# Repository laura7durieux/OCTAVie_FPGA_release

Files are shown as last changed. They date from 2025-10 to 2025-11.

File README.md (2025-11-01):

# OCTAVie – Ultrasonic Acquisition Platform

**OCTAVie** is an open-source hardware and software platform designed to capture and analyze ultrasonic vocalizations of animals (up to ≥80 kHz).  
It combines a sensitive microphone module, an analog front-end, an FPGA-based acquisition unit, and a PC application for real-time spectral analysis.

This repository hosts the **complete open-source design files**: electronics, enclosures, FPGA firmware, PC software, documentation, and example datasets.  
The project is developed at **ICube, LNCA, and the Faculty of Physics and Engineering – Strasbourg, France**, within the framework of the **OCTAVie project**.

---

## Quickstart

### 1. Build Hardware
- Go to [hardware/](hardware/)  
- Assemble the **microphone** and the **acquisition unit** following the build guide:  
  - [docs/build_guide/pcb_assembly.md](docs/build_guide/pcb_assembly.md)  
  - [docs/build_guide/mechanical_assembly.md](docs/build_guide/mechanical_assembly.md)  
- Complete system integration: [hardware/system_integration/final_assembly.md](hardware/system_integration/final_assembly.md)

### 2. Program FPGA
- Go to [firmware_fpga/](firmware_fpga/)  
- Compile the project in Quartus (or use provided bitstreams in [releases/](releases/))  
- Load bitstream on Cyclone V GX using Quartus Programmer

### 3. Run PC Application
- Go to [software_pc/](software_pc/)  
- Install dependencies
- Run the software

### Documentation
- Build guide → docs/build_guide/
- User guide → docs/user_guide/user_manual.md
- Validation & tests → docs/validation/
- BOM → docs/publication_assets/tables/bom_master_v1.0.csv

### Citation
If you use this project, please cite the associated HardwareX article and Zenodo DOI:
10.5281/zenodo.17356089

### License
- Hardware → CERN OHL-S v2.0
- Software → GPL-3.0
- Documentation → CC BY-SA 4.0
(see LICENSES/)

---

## Repository Structure
Please see the document : File_list_V1.xlsx 
This document regroups all the documents available in this project as well as their localisation and their status.

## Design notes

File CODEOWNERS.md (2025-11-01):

### `CODEOWNERS`  
# This file defines code owners for automatic review assignment.

# Root files and general documentation
/ @LauraDurieux

# Hardware (PCB, CAD)
/hardware/ @LauraDurieux 

# FPGA firmware
/firmware_fpga/ @LauraDurieux

# PC software
/software_pc/ @JeanBaptisteK

# Documentation
/docs/ @LauraDurieux

# Default owner
* @LauraDurieux

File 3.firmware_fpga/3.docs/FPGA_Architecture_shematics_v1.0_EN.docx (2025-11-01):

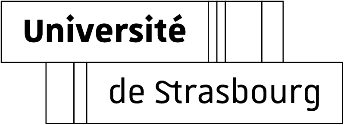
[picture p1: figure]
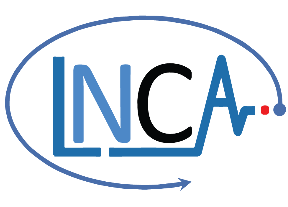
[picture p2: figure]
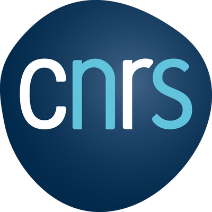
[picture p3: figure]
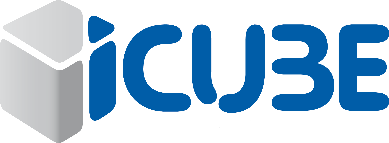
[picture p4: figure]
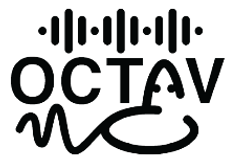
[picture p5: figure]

ie

L. Durieux

Abstract

This document presents an overview of the FPGA design implemented in Intel Quartus. Since the complete project files cannot be shared due to proprietary IP content, only a visual capture of the Quartus design is provided. The image illustrates the top-level architecture and interconnections between the main logic blocks used in the OCTAVie system, including acquisition, FFT processing, and communication modules. This overview aims to give readers a clear understanding of the FPGA design structure while respecting intellectual property constraints.

FPGA architecture schematic

English – v1.0

# Section 1 — FPGA Quartus schematic full view

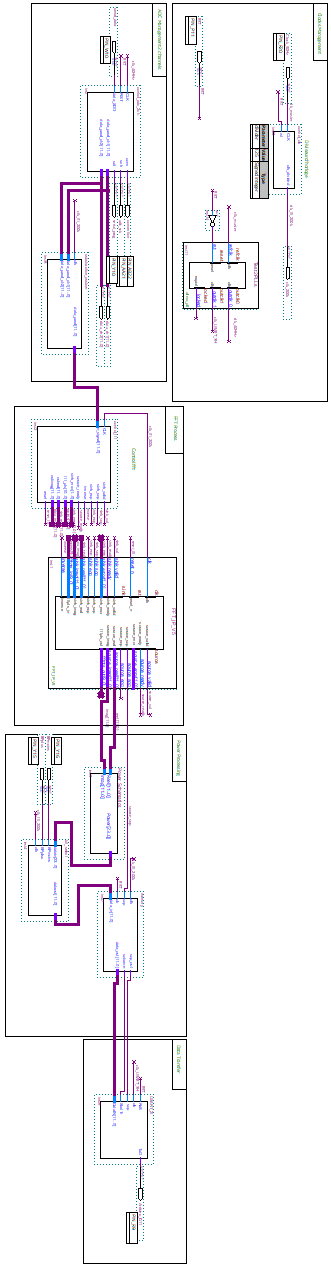
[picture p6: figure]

# Section 2 – Details on the subblocks

## Clocks management

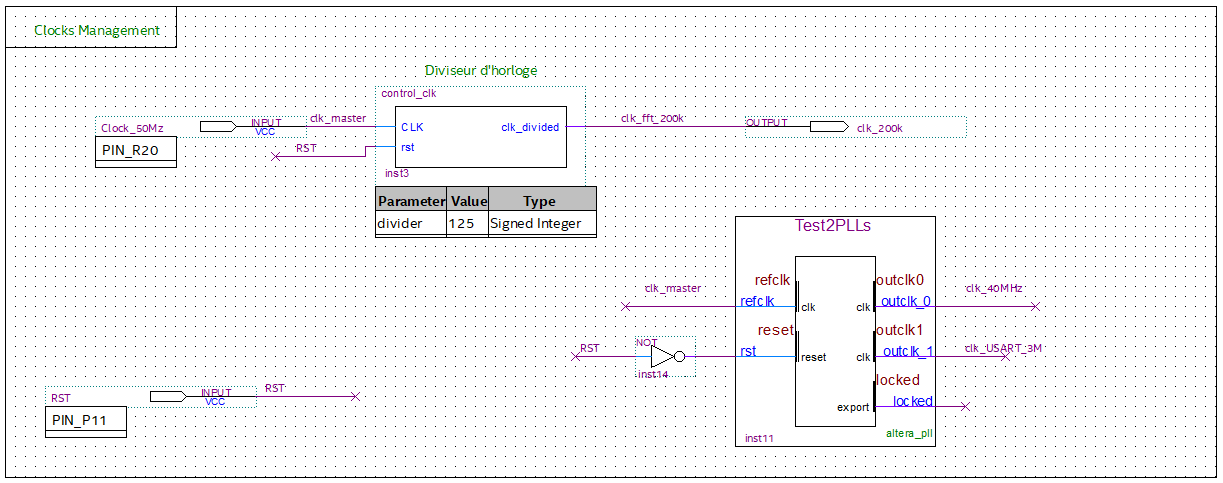
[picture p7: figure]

## ADC management 2channels

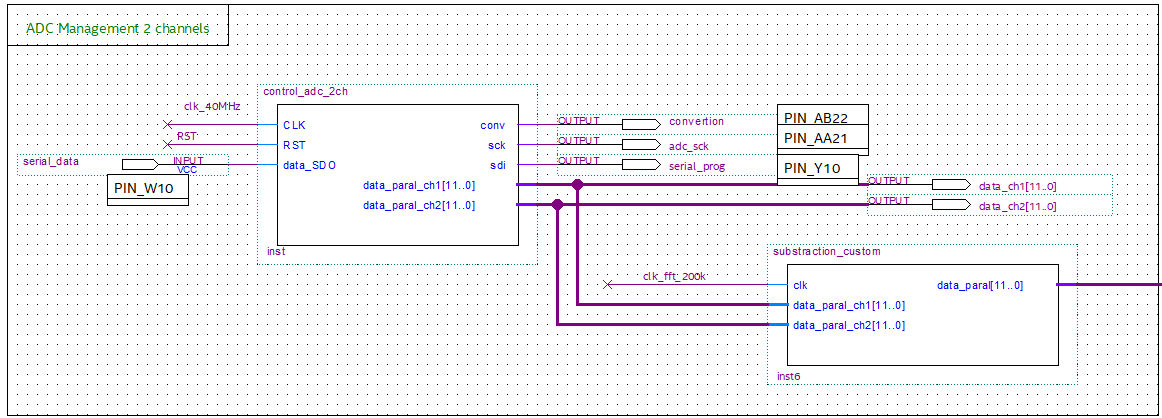
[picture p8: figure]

## FFT Process

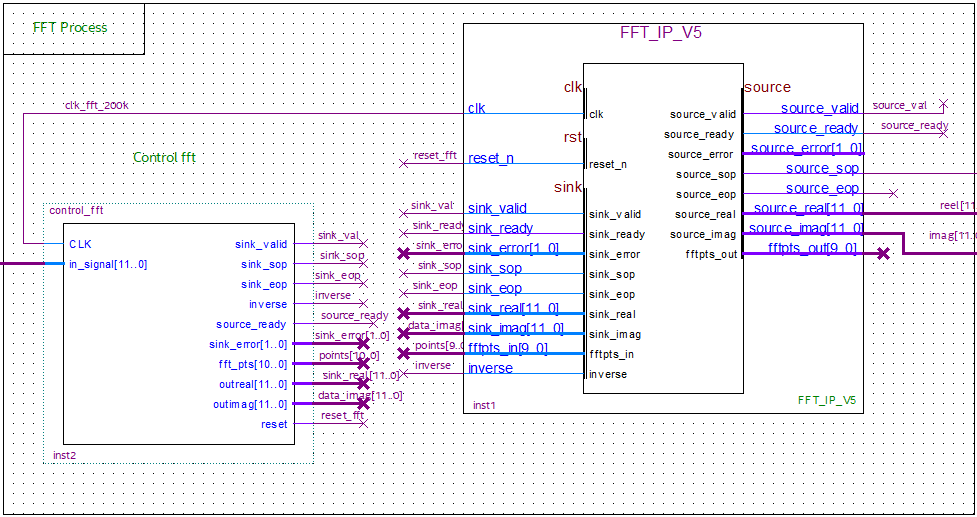
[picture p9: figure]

## Power processing

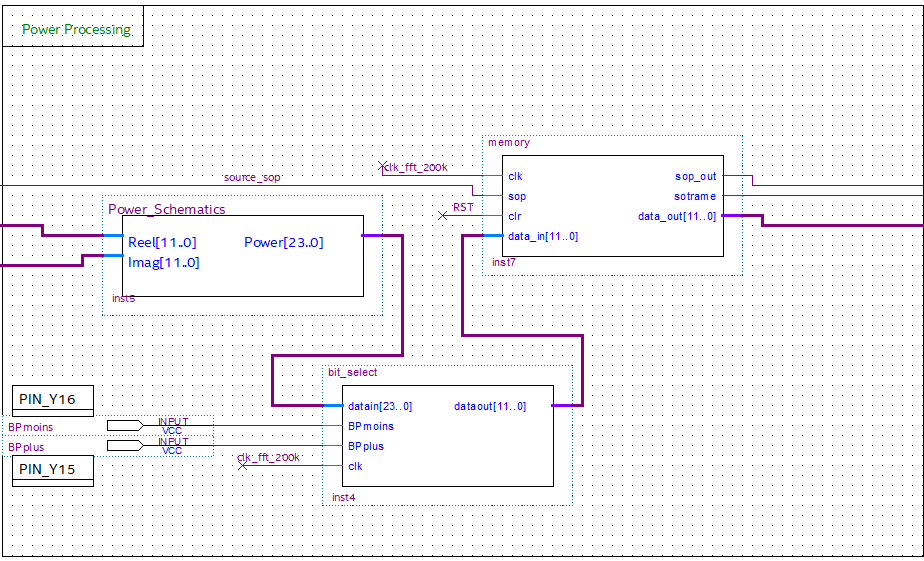
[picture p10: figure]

Inside Power Schematics:

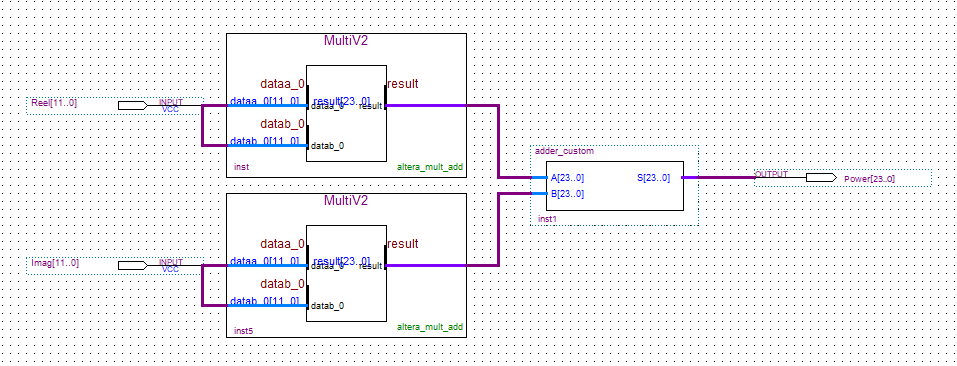
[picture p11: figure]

## Data Transfer

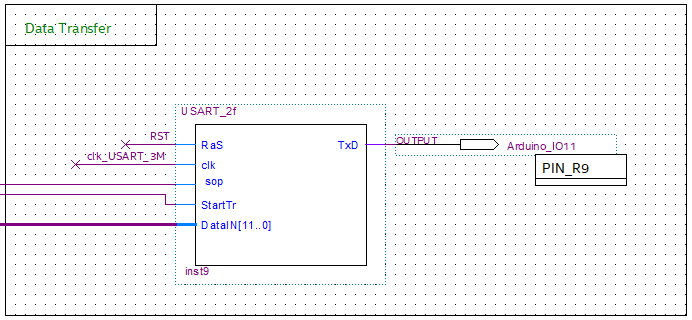
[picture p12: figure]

# Section 3 – list of the available modules

- adder_custom.vhd

Performs a simple 24-bit unsigned addition between two input vectors. Used for internal arithmetic operations such as sample accumulation or amplitude scaling.

- bit_select.vhd

Implements a dynamic bit-window selector controlled by two push buttons. Allows the user to manually choose a 12-bit slice within a 24-bit signal, useful for debugging or signal inspection.

- control_adc_2ch.vhd

Controls a two-channel ADC via a bit-banged SPI protocol. Manages conversion timing, serial data readout, and channel configuration for alternating acquisition between channel 1 and channel 2.

- control_clk.vhd

A simple clock divider generating a lower-frequency clock from the main 50 MHz input. Used to derive timing signals for slower subsystems such as the ADC interface or FFT logic.

- control_fft.vhd

Generates the control interface for an FFT IP core (start, end, valid, and reset).
Feeds the FFT block with real input samples, handles SOP/EOP markers, and produces a short reset pulse during startup.

- memory.vhd

Implements a 256×12-bit synchronous RAM buffer with simultaneous write and read operations. Used to temporarily store and replay sample data, synchronized with a “start of packet” (SOP) trigger.

- substraction_custom.vhd

Performs a signed subtraction between two 12-bit input channels. Used to compute differential signals (e.g., between ADC channels) before FFT processing.

- USART_2f.vhd

Custom two-frame UART transmitter that serializes 12-bit data over two consecutive UART-like frames. Each frame includes start, data, and stop bits, plus embedded SOP flag bits for synchronization.

What is not included are the blocks IP of INTEL Namely:

- MultiV2
- FFT_IP_V5
- Test2PLLs

To be able to redo the full schematic you need to buy these blocks. Note that, to simply program the FPGA with the current version without modifying the function, you can simply use bitstream.

# License Information

Hardware license: CERN Open Hardware License v2 (Strongly Reciprocal – OHL-S).

Software license: GNU General Public License v3 (GPLv3), ensuring that all modifications remain open-source.

Documentation license: Creative Commons Attribution-ShareAlike 4.0 International (CC-BY-SA 4.0).

# Versioning

Authors | Version | Date | Comment
L. Durieux | V1.0 | 29.10.2025 | Document first release
F. STOCK | | 01.11.2025 | Review

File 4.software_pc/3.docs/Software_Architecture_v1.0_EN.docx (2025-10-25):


ie

JB Kammerer

Abstract

This document presents the software architecture of the OCTAVie system. It aims to facilitate the understanding of the provided source code by illustrating the main program flow and interactions between modules through a simplified flowchart. The diagram highlights the sequence from data acquisition and FPGA communication to signal processing, display, and file storage. This overview helps readers grasp the overall logic and structure of the software for easier maintenance, customization, and further development.

Software Architecture

English – v1.0

# Section 1 — Structure Generale

To be completed

# License Information

Hardware license: CERN Open Hardware License v2 (Strongly Reciprocal – OHL-S).

Software license: GNU General Public License v3 (GPLv3), ensuring that all modifications remain open-source.

Documentation license: Creative Commons Attribution-ShareAlike 4.0 International (CC-BY-SA 4.0).

# Versioning

Authors | Version | Date | Comment
JB Kammerer | V1.0 | 25.10.25 | Document first release

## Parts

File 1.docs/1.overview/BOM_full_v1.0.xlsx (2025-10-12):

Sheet: Details
Designator | Component | Number | Cost per unit (€) | Total cost (€) | Source of materials | Material type
Microphone
Electronic component
C1,C4 | C0805C104K5RACTU | 2 | 0.07 | 0.14 | DigiKey | Ceramic
C2,C3,C6 | C0805C105K3RACTU | 3 | 0.1 | 0.3 | DigiKey | Ceramic
C5 | C0805C474K5RACTU | 1 | 0.23 | 0.23 | DigiKey | Ceramic
R1 | AC0805FR-074K7L | 1 | 0.09 | 0.09 | DigiKey | Composite
R2 | RC0805JR-071KL | 1 | 0.1 | 0.1 | DigiKey | Composite
R3 | RC0805JR-0710KL | 1 | 0.09 | 0.09 | DigiKey | Composite
R4 | RC0805JR-071ML | 1 | 0.09 | 0.09 | DigiKey | Composite
R5 | RC0805JR-0718KL | 1 | 0.09 | 0.09 | DigiKey | Composite
R6,R7 | RC0805JR-07100KL | 2 | 0.01 | 0.09 | DigiKey | Composite
D1 | 150080RS75000 | 1 | 0.16 | 0.16 | DigiKey | Semiconductor
IC1 | MCP6021-I/SN | 1 | 1.19 | 1.19 | DigiKey | Semiconductor
U1 | IMP23ABSUTR | 1 | 2.22 | 2.22 | DigiKey | Semiconductor
J1 | B3B-PH-SM4-TB | 1 | 0.45 | 0.45 | DigiKey | Composite
Total |  |  | 4.89 | 5.24
PCBA
PCB Fabrication |  | 1 | 5.98 | 5.98 | JLCPCB | Other
PCB Assembly |  | 1 | 0 | 0 | JLCPCB | Other
Shipping |  | 1 | 18.37 | 18.37 | JLCPCB | Other
Total |  |  | 24.35 | 24.35
System assembly
Sound cable | 8451 010100 | 2 m | 3.44 | 51.61 | DigiKey | Composite
XLR male | AC3MM | 1 | 3.36 | 3.36 | DigiKey | Composite
JST female | PHR-3 | 1 | 0.09 | 0.09 | DigiKey | Composite
Total |  |  | 6.89 | 55.06
Enclosure
3D printing |  | 1 | 2.63 | 2.63
Total |  |  | 12.97 | 61.14
Total Microphone |  |  | 38.76 | 87.28
Analog Signal Board
Electronic component
C1 | 10 µF capacitor (C0805C106K8PACTU) | 1 | 0.11 | 0.11 | DigiKey | Ceramic
C2,C6,C18 | 1 µF capacitor (C0805C105K3RAC7800) | 3 | 0.1 | 0.3 | DigiKey | Ceramic
C3,C14,C26 | 100 nF capacitor (C0805C104M5RAC7800) | 3 | 0.09 | 0.27 | DigiKey | Ceramic
C4,C11,C12,C13,C16,C23,C24,C25 | 1 nF capacitor (C0805C102K1HAC7800) | 8 | 0.09 | 0.72 | DigiKey | Ceramic
C5,C10,C17,C22 | 1.5 nF capacitor (C0805C152K3HAC7800) | 4 | 0.09 | 0.36 | DigiKey | Ceramic
C7,C19 | 100 pF capacitor (C0805C101J5GAC7800) | 2 | 0.07 | 0.14 | DigiKey | Ceramic
C8,C20 | 180 pF capacitor (C0805C181K5GAC7800) | 2 | 0.2 | 0.4 | DigiKey | Ceramic
C9,C21 | 15 nF capacitor (C0805C153K5RAC7800) | 2 | 0.09 | 0.18 | DigiKey | Ceramic
C15,C27 | 470 pF capacitor (C0805C471K5RAC7800) | 2 | 0.09 | 0.18 | DigiKey | Ceramic
J1,J3,J9,J10 | 3-pin JST connector (B3B-XH-A) | 4 | 0.09 | 0.36 | DigiKey | Composite
J2,J4,J5,J13 | 2-pin header (PH1-02-UA) | 4 | 0.09 | 0.36 | DigiKey | Composite
J6,J14 | 2x3-pin header (PH2-06-UA) | 2 | 0.09 | 0.18 | DigiKey | Composite
J7,J8 | 1-pin header (PH1-01-UA) | 2 | 0.08 | 0.16 | DigiKey | Composite
J11 | 8-pin header (PH1-08-UA) | 1 | 0.09 | 0.09 | DigiKey | Composite
J12 | 6-pin JST connector (B6B-XH-A) | 1 | 0.15 | 0.15 | DigiKey | Composite
R1,R2,R3,R4,R11,R12,R20,R24,R26,R27,R28,R29,R36,R37,R43,R48,RV1,RV2 | Resistor 100kΩ (ERJ-P06J104V) | 18 | 0.1 | 1.8 | DigiKey | Other
R5,R6,R30,R31 | Resistor 3.9kΩ (ERJ-P06J392V) | 4 | 0.1 | 0.4 | DigiKey | Other
R7,R32 | Resistor 560Ω (ERJ-P06J561V) | 2 | 0.1 | 0.2 | DigiKey | Other
R8,R10,R33,R35 | Resistor 15kΩ (ERJ-P06J153V) | 4 | 0.1 | 0.4 | DigiKey | Other
R9,R34 | Resistor 1.2kΩ (ERJ-P06J122V) | 2 | 0.1 | 0.2 | DigiKey | Other
R13,R38 | Resistor 5.6kΩ (ERJ-P06J562V) | 2 | 0.1 | 0.2 | DigiKey | Other
R14,R18,R39,R44 | Resistor 82kΩ (ERJ-P06J823V) | 4 | 0.1 | 0.4 | DigiKey | Other
R15,R19,R40,R45 | Resistor 33kΩ (ERJ-P06J333V) | 4 | 0.1 | 0.4 | DigiKey | Other
R16,R25,R42,R50 | Resistor 100Ω (ERJ-P06J101V) | 4 | 0.1 | 0.4 | DigiKey | Other
R17,R21,R23,R41,R46,R47 | Resistor 10kΩ (ERJ-P06J103V) | 6 | 0.1 | 0.6 | DigiKey | Other
R22,R49 | Resistor 1kΩ (ERJ-P06J102V) | 2 | 0.1 | 0.2 | DigiKey | Other
U1,U4 | Integrated Circuit - MCP6022 (dual op amp) | 2 | 1.82 | 3.64 | DigiKey | Semiconductor
U2,U5 | Integrated Circuit - MCP6024 (quad op amp) | 2 | 2.4 | 4.8 | DigiKey | Semiconductor
U3,U6 | Integrated Circuit - MCP6021 (single op amp) | 2 | 1.46 | 2.92 | DigiKey | Semiconductor
H_Uno_10 | 10-pin header (PH1-10-UA) | 1 | 0.12 | 0.12 | DigiKey | Composite
H_Uno_8 | 8-pin header (PH1-08-UA) | 2 | 0.09 | 0.18 | DigiKey | Composite
H_Uno_6 | 6-pin header (PH1-06-UA) | 1 | 0.09 | 0.09 | DigiKey | Composite
Total |  |  | 8.6 | 20.91
PCBA
PCB Fabrication |  | 1 | 5.98 | 5.98 | JLCPCB | Other
PCB Assembly |  | 1 | 0 | 0 | JLCPCB | Other
Shipping |  | 1 | 18.37 | 18.37 | JLCPCB | Other
Total |  |  | 24.35 | 24.35
Total Analog Signal Board |  |  | 32.95 | 45.26
FPGA
Electronic component
FPGA - Cyclone V GX - dev. Kit | P0150 | 1 | 264.63 € | 264.63 € | Mouser | Other
Total |  |  | 264.63 € | 264.63 €
Total FPGA |  |  | 264.63 | 264.63
System
System assembly
FTDI Cable | TTL-234X-3V3 | 1 | 17.35 | 17.35 | DigiKey | Composite
JST female 3 pin | XHP-3 | 3 | 0.09 | 0.27 | DigiKey | Composite
JST female 6 pin | XHP-6 | 1 | 0.064 | 0.064 | DigiKey | Composite
Potentiometer 100kohm | P160KNP-0QD20B100K | 2 | 1.61 | 3.22 | DigiKey | Composite
XLR female | AC3FAHL2-AU-PRE | 2 | 1.27 | 2.54 | DigiKey | Composite
Total |  |  | 20.38 | 23.44
Enclosure
3D printing |  | 1 | 36.87 | 36.87
Total |  |  | 36.87 | 36.87
Total System |  |  | 90.20 | 105.57
Grand Total |  |  | 426.54 | 502.74

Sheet: Sheet1
Designator | Number | Cost per unit (€) | Total cost (€) | Source of materials | Material type
Microphone
Electronic component | 1 | 4.89 | 5.24 | Digikey | Other
PCBA | 1 | 24.35 | 24.35 | JLCPCB | Other
System assembly | 1 | 6.89 | 55.06 | Digikey | Other
Enclosure | 1 | 12.97 | 61.14 | JLCPCB | Other
Analog Signal Board
Electronic component | 1 | 8.6 | 20.91 | Digikey | Other
PCBA | 1 | 24.35 | 24.35 | JLCPCB | Other
FPGA
Electronic component | 1 | 264.63 € | 264.63 € | Mouser | Other
System
System assembly | 1 | 20.38 | 23.44 | Digikey | Other
Enclosure | 1 | 36.87 | 36.87 | JLCPCB | Other
Total
 |  | 403.94 | 515.99

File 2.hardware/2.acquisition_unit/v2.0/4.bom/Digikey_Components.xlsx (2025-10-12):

Index | Quantité | Référence | Référence fabricant | Description | Référence client | Disponible | Articles différés | Prix unitaire | Prix calculé EUR
1 | 1 | 732-8491-1-ND | 865080243008 | CAP ALUM 150UF 20% 10V SMD |  | 1 | 0 | 0.26 | 0.26
2 | 1 | 732-8412-1-ND | 865080340002 | CAP ALUM 15UF 20% 16V SMD |  | 1 | 0 | 0.16 | 0.16
3 | 3 | 399-C0805C105K3RACTUCT-ND | C0805C105K3RACTU | CAP CER 1UF 25V X7R 0805 |  | 3 | 0 | 0.1 | 0.30
4 | 8 | 399-C0805C102K1HACTUCT-ND | C0805C102K1HACTU | CAP CER 1000PF 100V X8R 0805 |  | 8 | 0 | 0.09 | 0.72
5 | 4 | 399-C0805C152K3HACTUCT-ND | C0805C152K3HACTU | CAP CER 1500PF 25V X8R 0805 |  | 4 | 0 | 0.09 | 0.36
6 | 2 | 399-C0805C101J5GACTUCT-ND | C0805C101J5GACTU | CAP CER 100PF 50V C0G/NP0 0805 |  | 2 | 0 | 0.07 | 0.14
7 | 2 | 399-C0805C181K5GACTUCT-ND | C0805C181K5GACTU | CAP CER 180PF 50V C0G/NP0 0805 |  | 2 | 0 | 0.2 | 0.40
8 | 2 | 399-C0805C153K5RACTUCT-ND | C0805C153K5RACTU | CAP CER 0.015UF 50V X7R 0805 |  | 2 | 0 | 0.09 | 0.18
9 | 2 | 399-C0805C104M5RACTUCT-ND | C0805C104M5RACTU | CAP CER 0.1UF 50V X7R 0805 |  | 2 | 0 | 0.09 | 0.18
10 | 2 | 399-C0805C471K5RACTUCT-ND | C0805C471K5RACTU | CAP CER 470PF 50V X7R 0805 |  | 2 | 0 | 0.09 | 0.18
11 | 2 | 455-2248-ND | B3B-XH-A | CONN HEADER VERT 3POS 2.5MM |  | 2 | 0 | 0.11 | 0.22
12 | 2 | 2057-PH1-03-UA-ND | PH1-03-UA | CONN HEADER VERT 3POS 2.54MM |  | 2 | 0 | 0.09 | 0.18
13 | 1 | 2057-PH1-02-UA-ND | PH1-02-UA | CONN HEADER VERT 2POS 2.54MM |  | 1 | 0 | 0.09 | 0.09
14 | 3 | 2057-PH1-02-UA-ND | PH1-02-UA | CONN HEADER VERT 2POS 2.54MM |  | 3 | 0 | 0.09 | 0.27
15 | 2 | 2057-PH2-06-UA-ND | PH2-06-UA | CONN HEADER VERT 6POS 2.54MM |  | 2 | 0 | 0.1 | 0.20
16 | 2 | 2057-PH1-01-UA-ND | PH1-01-UA | CONN HEADER VERT 1POS 2.54MM |  | 2 | 0 | 0.09 | 0.18
17 | 1 | 2057-PH1-08-UA-ND | PH1-08-UA | CONN HEADER VERT 8POS 2.54MM |  | 1 | 0 | 0.09 | 0.09
18 | 1 | 2057-PH1-06-UA-ND | PH1-06-UA | CONN HEADER VERT 6POS 2.54MM |  | 1 | 0 | 0.09 | 0.09
19 | 18 | P100KADCT-ND | ERJ-P06J104V | RES SMD 100K OHM 5% 1/2W 0805 |  | 18 | 0 | 0.05 | 0.90
20 | 4 | P3.9KADCT-ND | ERJ-P06J392V | RES SMD 3.9K OHM 5% 1/2W 0805 |  | 4 | 0 | 0.1 | 0.40
21 | 2 | P560ADCT-ND | ERJ-P06J561V | RES SMD 560 OHM 5% 1/2W 0805 |  | 2 | 0 | 0.1 | 0.20
22 | 4 | P15KADCT-ND | ERJ-P06J153V | RES SMD 15K OHM 5% 1/2W 0805 |  | 4 | 0 | 0.1 | 0.40
23 | 2 | P1.2KADCT-ND | ERJ-P06J122V | RES SMD 1.2K OHM 5% 1/2W 0805 |  | 2 | 0 | 0.1 | 0.20
24 | 2 | P5.6KADCT-ND | ERJ-P06J562V | RES SMD 5.6K OHM 5% 1/2W 0805 |  | 2 | 0 | 0.1 | 0.20
25 | 4 | P82KADCT-ND | ERJ-P06J823V | RES SMD 82K OHM 5% 1/2W 0805 |  | 4 | 0 | 0.1 | 0.40
26 | 4 | P33KADCT-ND | ERJ-P06J333V | RES SMD 33K OHM 5% 1/2W 0805 |  | 4 | 0 | 0.1 | 0.40
27 | 4 | P100ADCT-ND | ERJ-P06J101V | RES SMD 100 OHM 5% 1/2W 0805 |  | 4 | 0 | 0.1 | 0.40
28 | 6 | P10KADCT-ND | ERJ-P06J103V | RES SMD 10K OHM 5% 1/2W 0805 |  | 6 | 0 | 0.1 | 0.60
29 | 2 | P1.0KADCT-ND | ERJ-P06J102V | RES SMD 1K OHM 5% 1/2W 0805 |  | 2 | 0 | 0.1 | 0.20
30 | 2 | MCP6022T-I/SNCT-ND | MCP6022T-I/SN | IC OPAMP GP 2 CIRCUIT 8SOIC |  | 2 | 0 | 1.55 | 3.10
31 | 2 | MCP6024-I/SL-ND | MCP6024-I/SL | IC OPAMP GP 4 CIRCUIT 14SOIC |  | 2 | 0 | 2.24 | 4.48
32 | 2 | MCP6021-I/SN-ND | MCP6021-I/SN | IC OPAMP GP 1 CIRCUIT 8SOIC |  | 2 | 0 | 1.19 | 2.38

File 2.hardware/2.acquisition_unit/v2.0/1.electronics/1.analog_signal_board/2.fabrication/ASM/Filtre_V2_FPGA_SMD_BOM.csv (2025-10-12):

 | Sourced | Placed | References | Value | Footprint | Quantity
1 |  |  | C4, C11, C12, C13, C16, C23, C24, C25 | 1nF | C_0805_2012Metric | 8
2 |  |  | C5, C10, C17, C22 | 1.5nF | C_0805_2012Metric | 4
3 |  |  | C2, C6, C18 | 1µF | C_0805_2012Metric | 3
4 |  |  | C3, C14, C26 | 100nF | C_0805_2012Metric | 3
5 |  |  | C7, C19 | 100pF | C_0805_2012Metric | 2
6 |  |  | C8, C20 | 180pF | C_0805_2012Metric | 2
7 |  |  | C9, C21 | 15nF | C_0805_2012Metric | 2
8 |  |  | C15, C27 | 470pF | C_0805_2012Metric | 2
9 |  |  | C1 | 10µF | C_0805_2012Metric | 1
10 |  |  | R1, R2, R3, R4, R11, R12, R20, R24, R26, R27, R28, R29, R36, R37, R43, R48, RV1, RV2 | 100k | R_0805_2012Metric, JST_XH_B3B-XH-AM_1x03_P2.50mm_Vertical | 18
11 |  |  | R17, R21, R23, R41, R46, R47 | 10k | R_0805_2012Metric | 6
12 |  |  | R5, R6, R30, R31 | 3.9k | R_0805_2012Metric | 4
13 |  |  | R8, R10, R33, R35 | 15k | R_0805_2012Metric | 4
14 |  |  | R14, R18, R39, R44 | 82k | R_0805_2012Metric | 4
15 |  |  | R15, R19, R40, R45 | 33k | R_0805_2012Metric | 4
16 |  |  | R16, R25, R42, R50 | 100 | R_0805_2012Metric | 4
17 |  |  | R7, R32 | 560 | R_0805_2012Metric | 2
18 |  |  | R9, R34 | 1.2k | R_0805_2012Metric | 2
19 |  |  | R13, R38 | 5.6k | R_0805_2012Metric | 2
20 |  |  | R22, R49 | 1k | R_0805_2012Metric | 2
21 |  |  | U1, U4 | MCP6L02x-xMS | SOIC-8_3.9x4.9mm_P1.27mm | 2
22 |  |  | U2, U5 | MCP6L04x-xSL | SOIC-14_3.9x8.7mm_P1.27mm | 2
23 |  |  | U3, U6 | MCP6L91RT-ESN | SOIC-8_3.9x4.9mm_P1.27mm | 2
24 |  |  | A1 | Arduino_UNO_R3 | Arduino_UNO_R3 | 1
25 |  |  | J1, J3, J9, J10 | Conn_01x03_Socket | JST_XH_B3B-XH-AM_1x03_P2.50mm_Vertical, PinHeader_1x03_P2.54mm_Vertical | 4
26 |  |  | J4, J5, J13 | Conn_01x02_Pin | PinHeader_1x02_P2.54mm_Vertical, PinSocket_1x02_P2.54mm_Vertical | 3
27 |  |  | J6, J14 | Conn_02x03_Top_Bottom | PinHeader_2x03_P2.54mm_Vertical | 2
28 |  |  | J7, J8 | Conn_01x01_Pin | PinHeader_1x01_P2.54mm_Vertical | 2
29 |  |  | J2 | Conn_01x02_Socket | PinHeader_1x02_P2.54mm_Vertical | 1
30 |  |  | J11 | Conn_01x08_Socket | PinHeader_1x08_P2.54mm_Vertical | 1
31 |  |  | J12 | Conn_01x06_Socket | PinHeader_1x06_P2.54mm_Vertical | 1

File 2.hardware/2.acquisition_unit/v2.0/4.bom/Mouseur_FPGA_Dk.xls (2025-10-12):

PANIER
Ceci n'est pas une facture
25-août-25 01:42:36
 | N° Mouser | N° de fab. | Fabricant | N° client | Description | RoHS | Cycle de vie | Qté. | Prix (EUR) | Ext. : (EUR)
1 | 993-P0150 | P0150 | Terasic |  | Outils de développement de circuits intégrés logiques programmables Cyclone V GX Starter Kit | RoHS : conforme |  | 2 | 264,63 € | 529,26 €
En soumettant votre commande, vous acceptez ces conditions. (https://www.mouser.fr/saleterms) |  |  |  |  |  |  |  |  | Marchandise : | 529,26 €
Les prix sont ceux de la date et de l'heure indiquées. |  |  |  |  |  |  |  |  | Frais d'expédition : | 0,00 €

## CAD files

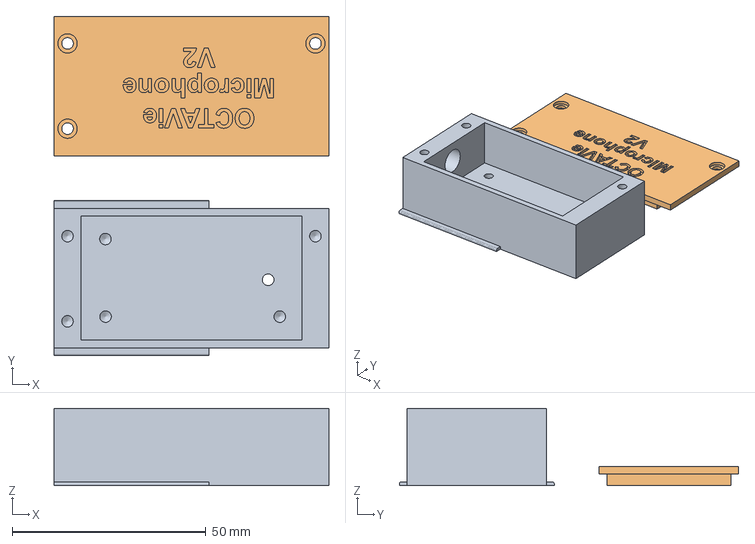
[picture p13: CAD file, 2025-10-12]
7.releases/1.microphone/2.enclosure/Full_Enclosure_v1.0.3mf
71.0 x 87.6 x 20.0 mm
Box.stl
Couvercle.stl

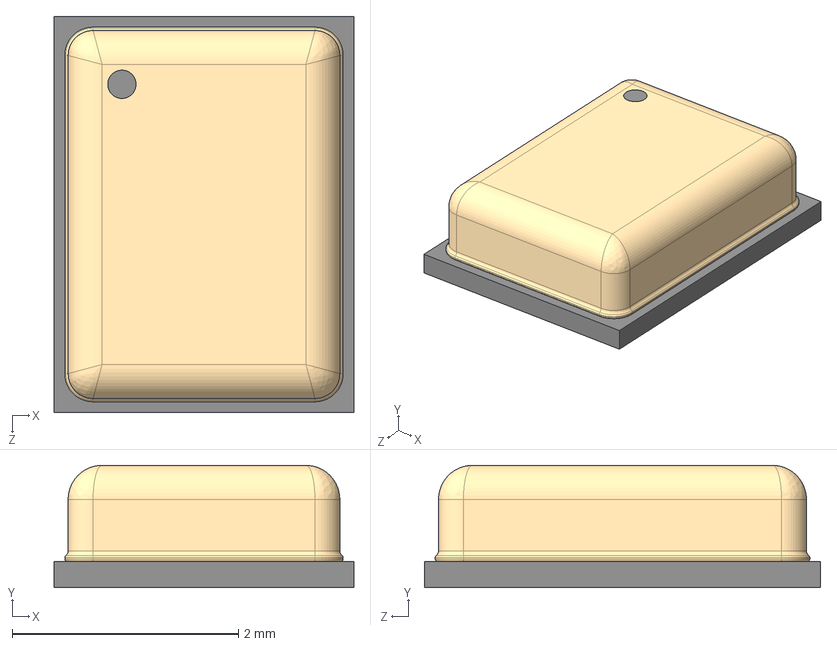
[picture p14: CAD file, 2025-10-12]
2.hardware/1.microphone/v1.0/1.electronics/1.pcb_design/IMP23ABSUTR/IMP23ABSUTR.step
2.65 x 1.08 x 3.50 mm

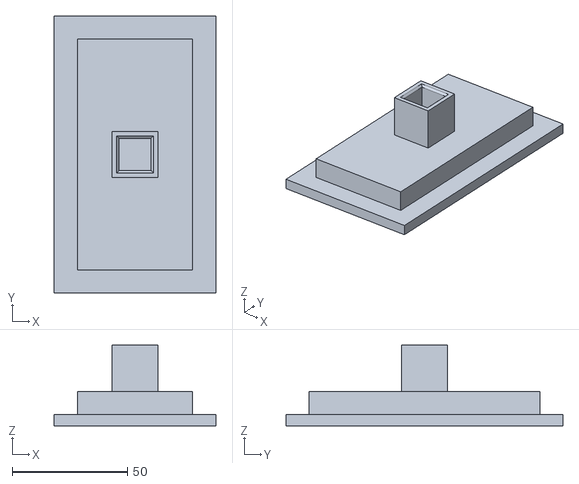
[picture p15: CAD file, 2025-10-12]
2.hardware/1.microphone/v1.0/2.enclosure/1.cad/Support_Foot_v1.0.stl
70.0 x 120.0 x 35.0

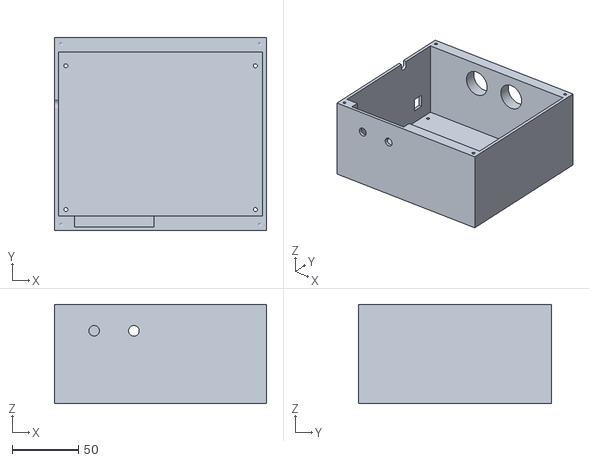
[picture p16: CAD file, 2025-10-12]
2.hardware/2.acquisition_unit/v2.0/2.enclosure/1.cad/BoiteFPGA_Body_v1.0.stl
160.0 x 146.0 x 75.0

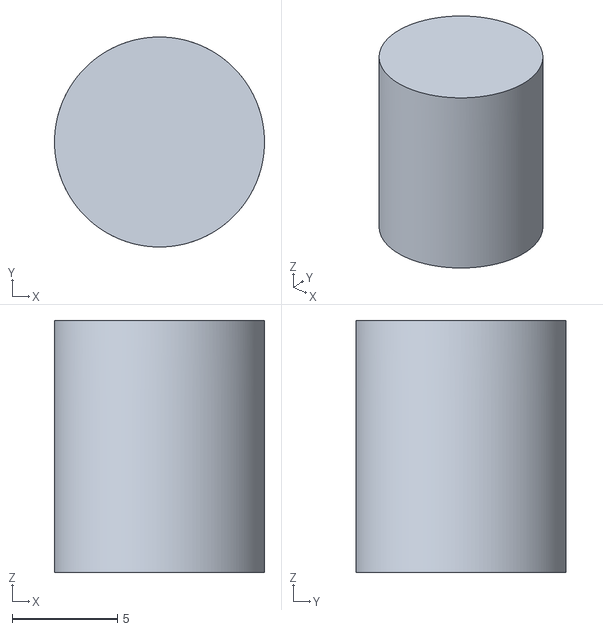
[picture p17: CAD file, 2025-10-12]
7.releases/2.acquisition_unit/2.enclosure/BoiteFPGA_ButtonPotentiometre_v1.0.stl
10.0 x 10.00 x 12.0

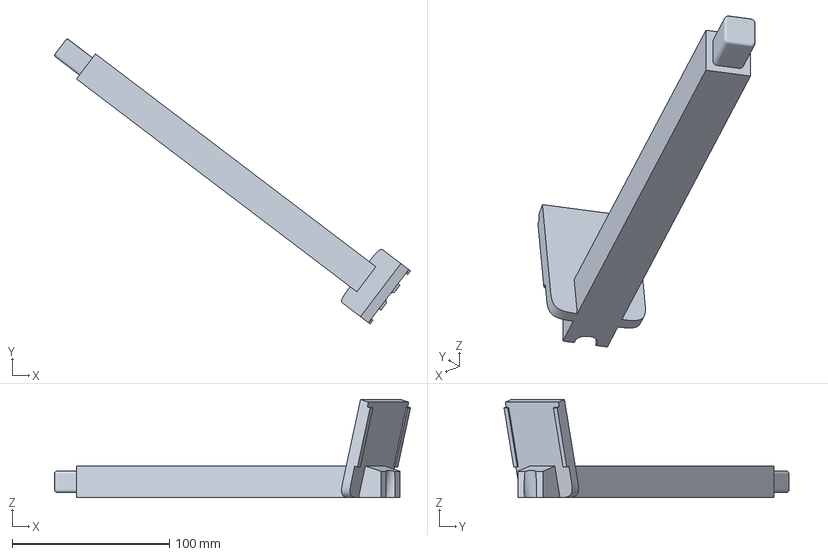
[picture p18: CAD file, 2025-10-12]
2.hardware/1.microphone/v1.0/2.enclosure/1.cad/Support_v1.0.3mf
226.2 x 181.1 x 62.3 mm

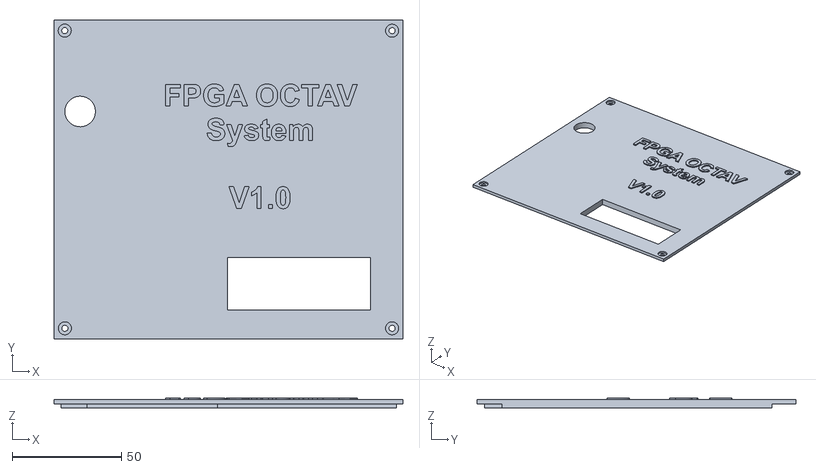
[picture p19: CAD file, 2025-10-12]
2.hardware/2.acquisition_unit/v2.0/2.enclosure/1.cad/BoiteFPGA_Couvercle_v1.0.stl
159.8 x 146.3 x 4.70

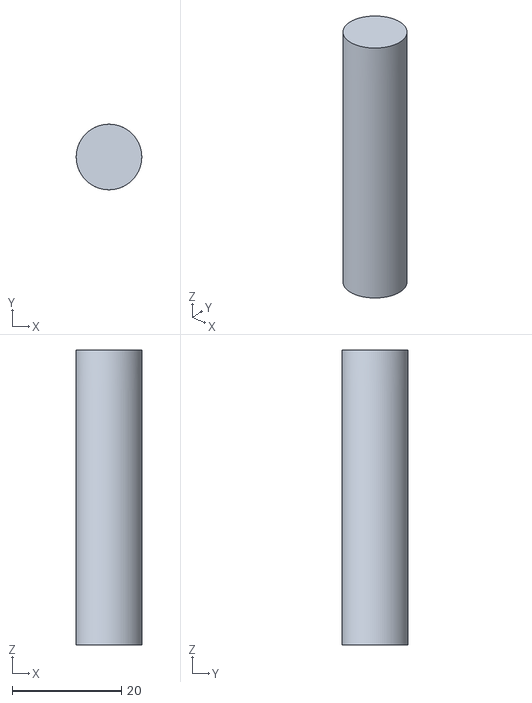
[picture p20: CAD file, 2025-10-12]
7.releases/2.acquisition_unit/2.enclosure/BoiteFPGA_Button_v1.0.stl
12.0 x 12.0 x 54.0

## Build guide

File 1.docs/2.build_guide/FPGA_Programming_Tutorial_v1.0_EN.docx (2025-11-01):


ie

L. Durieux

Abstract

This tutorial guides users through programming a Cyclone V FPGA with Quartus using a .pof file. It covers board preparation, hardware setup, file loading, and final configuration, ensuring a reliable workflow for flashing and testing the FPGA.

FPGA ProGramMing Tutorial

English – v1.0

# Introduction

This step-by-step tutorial explains how to program the Cyclone V FPGA board using the provided VHDL design file. It assumes you already have Quartus installed, the board powered and connected, and the .pof file ready.

# Step 1 – Prepare the FPGA board

- Plug in the FPGA power supply.
- Turn on the board using the red ON/OFF switch.
- Flip the small switch to the 'programming' position (left).
- Connect the USB-Blaster cable to the rectangular port on the top left and link it to your computer.

# Step 2 – Launch Quartus

- Open Quartus (Quartus Prime Lite used here – version 21.1).
- In the top menu, go to 'Tools' > 'Programmer'.

Example interface:

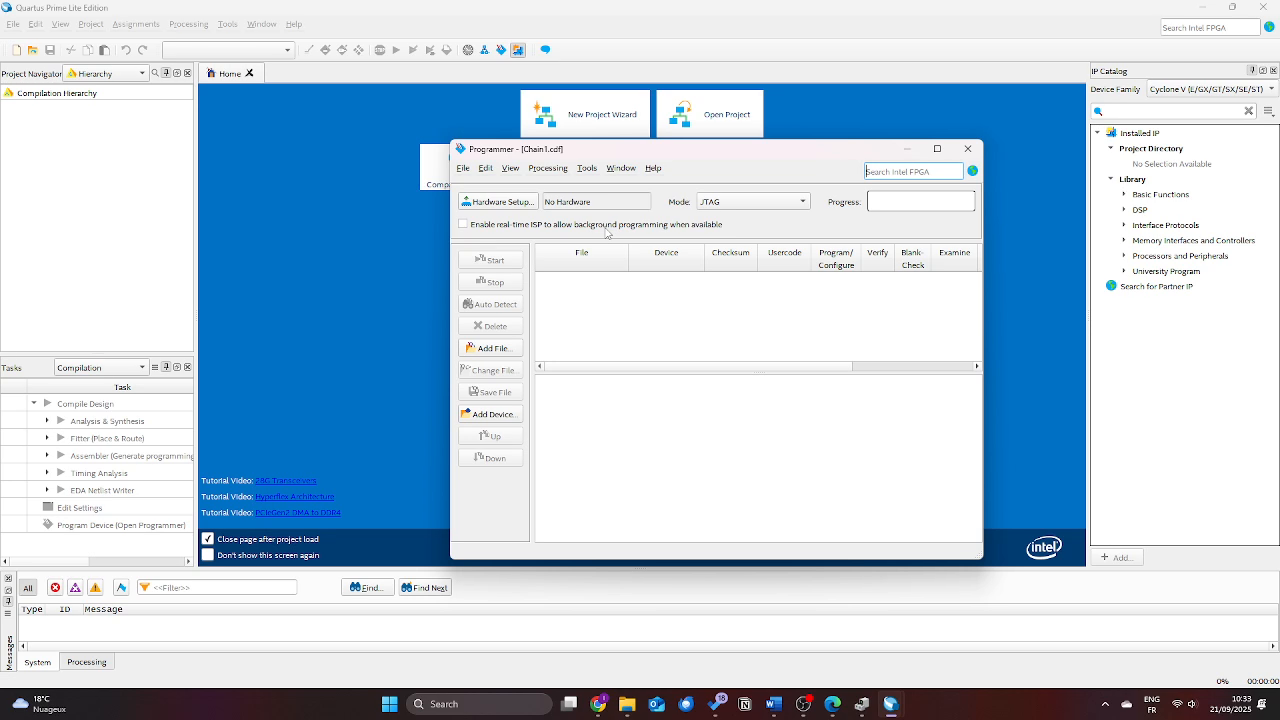
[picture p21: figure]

Note: If you have issues with installing Quartus Prime Lite, please, do not hesitate to contact us.

# Step 3 – Set up the hardware interface

- In the Programmer window, click on 'Hardware Setup...'.
- In the 'Currently selected hardware' field, choose 'USB-Blaster'.
- Close the window once selected.

Example interface:

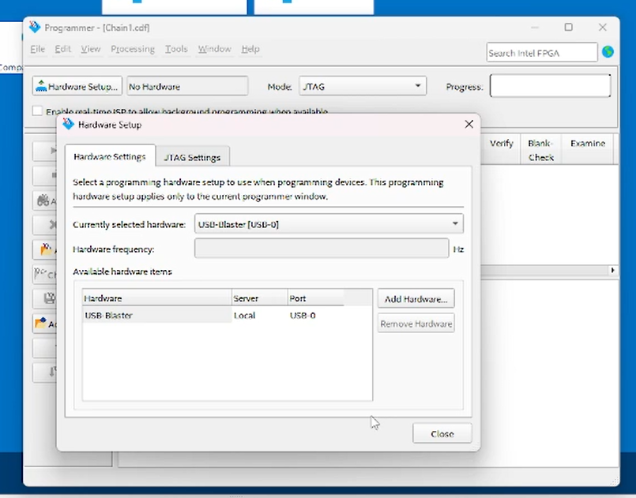
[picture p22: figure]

# Step 4 – Load the .pof file

- Click on 'Add File...' in the Programmer window.
- Browse to the .pof file location (e.g., `output_files.pof`). .pof is the bitstream file and it is the one we need to upload to the FPGA.
- Make sure the “mode” is set to 'Active Serial Programming' (not JTAG).
- Check the 'Program/Configure' and optionally 'Verify' boxes.

Example interface:

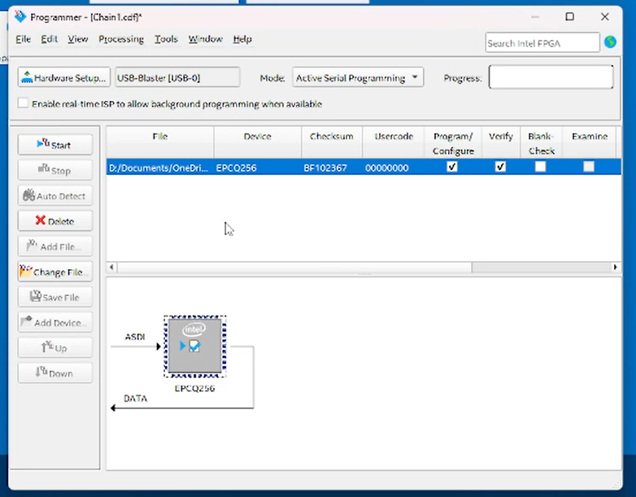
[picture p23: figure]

# Step 5 – Start the programming

- Click 'Start'. The programming process begins.
- Do not disconnect the board during this phase – it may take 20–30 minutes.
- Once the progress bar is fully green, programming is complete.

Example interface:

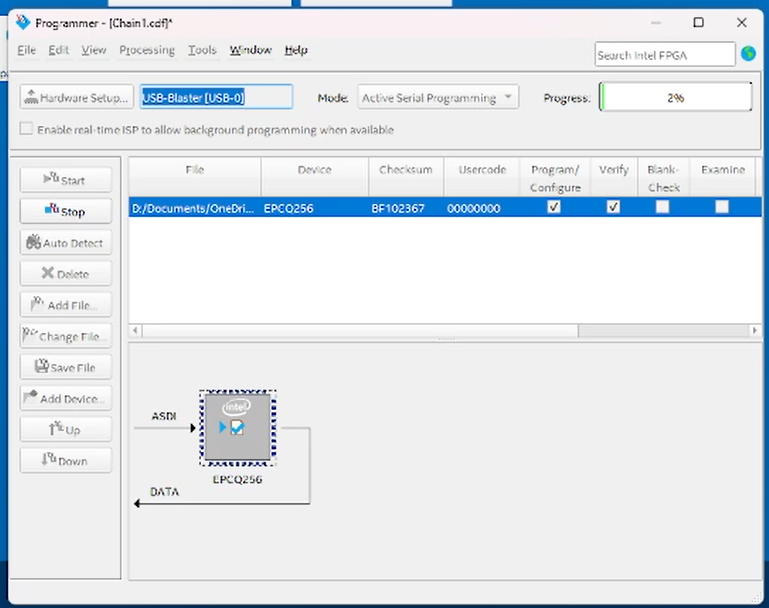
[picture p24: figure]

# Step 6 – Finalize setup

- Flip the switch back to 'Run'.
- You can now test the FPGA to verify the new configuration.

# Additional Notes

- The .pof file will be available in the open-source repository (GitHub or Zenodo). Make sure to use the correct version matching your hardware.
- If Quartus shows an error regarding the USB-Blaster, ensure drivers are installed and Quartus has administrator rights.
- You can repeat the process to flash multiple boards, starting again from Step 4.

# Versioning

Authors | Version | Date | Comment
L. Durieux | V1.0 | 23.09.25 | Document first release
A. Barbelivien M. MAJCHRzAK | | 01.11.25 | Proofreading

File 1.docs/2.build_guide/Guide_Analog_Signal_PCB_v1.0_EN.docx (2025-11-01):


ie

L. Durieux

Abstract

This guide explains how to prepare the Analog Signal PCB by cleaning flux residues and adjusting the differentiator stage. Simple steps with jumpers and potentiometers allow users to optimize frequency response for reliable signal recordings.

Guide Analog SIGNAL pcb

English – v1.0

# Introduction

When you receive the Analog Signal PCB, it is already assembled and ready to use. However, to ensure optimal performance and remove any manufacturing residues, it is important to clean the board before use. Then, with a few simple adjustments, you can adapt the board’s response to your experimental conditions.

This step-by-step guide will show you how to:
1. Properly clean the board.
2. Identify and understand the available adjustments.
3. Tune the board according to your recording needs.

# 1. Receiving the board

Upon delivery, the board arrives fully assembled with all components soldered. Assembly quality is usually good, but there are often traces of solder flux remaining.

# 2. Cleaning the board

Before using the board, it is recommended to remove any solder flux residues. For this, use ready-to-use wipes soaked in isopropyl alcohol. They provide a simple, quick, and effective cleaning method.

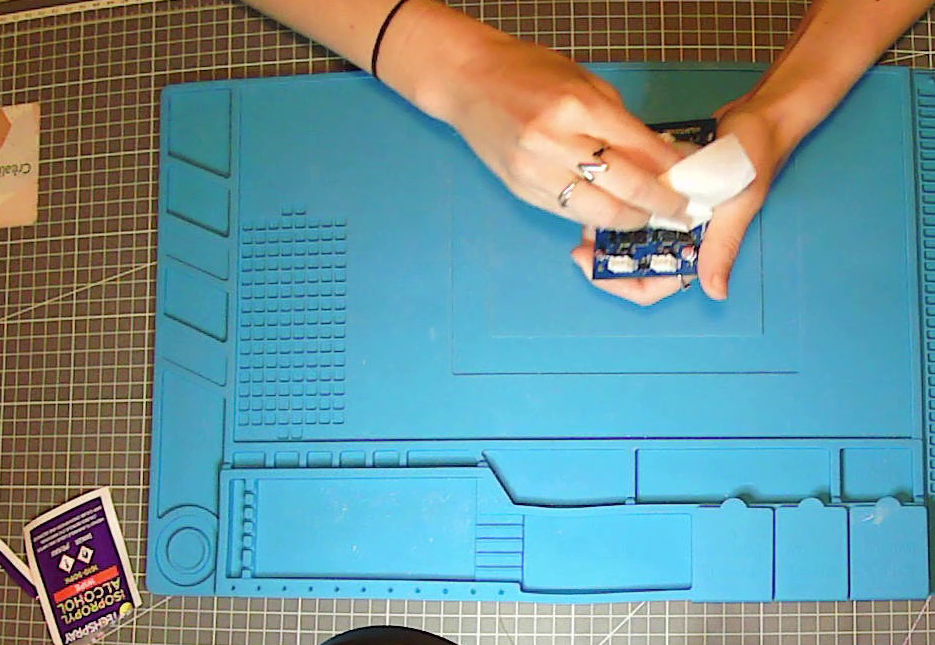
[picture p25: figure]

Practical tips:
- Gently wipe the surface of the board with the alcohol wipe.
- Allow the board to dry for a few seconds before handling.

# 3. Available adjustments

The board has two main adjustments that influence how the signal is processed:
- Whether or not the differentiator is active (J3 for channel 1; J10 for channel 2).
- The jumpers that controls the amplification of higher frequencies (J6 for channel 1; J14 for channel 2).

## 3.1 Enabling or disabling the differentiator

By default, a jumper (small black connector) is placed to activate the differentiator.
If you wish to disable the differentiator, move the jumper to the two upper pins.

Expected effect:
- With differentiator: higher frequencies are more strongly amplified.
- Without differentiator: the signal bypasses the differentiator.

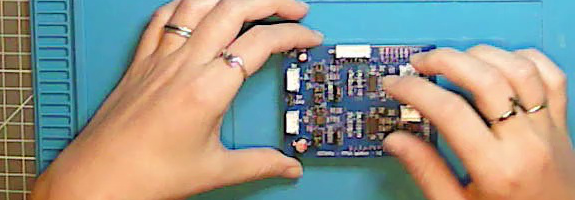
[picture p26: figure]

## 3.2 Adjusting the differentiator effect

In addition to the previous jumper, another jumper (2x3 pins header) allows fine-tuning of the amplification applied to higher frequencies.

- Moving it upwards: reduces the effect of the differentiator.
- Moving it downwards: increases the effect of the differentiator.

Practical tip: always start with the jumper set in the middle position. Then adjust according to test recordings (for example depending on distance or type of signal captured).

# 4. Verification after adjustment

Once cleaning and adjustments are done:
1. Connect the board to your system (computer + acquisition software).
2. Perform a test recording.
3. Check if the obtained spectrum matches your expectations.

Adjust the jumpers if necessary and keep the position that gives the best results for your experimental setup.

# Conclusion

To summarize:
- Clean the board upon receipt using ready-to-use isopropyl alcohol wipes.
- Choose the differentiator configuration according to your needs.
- Adjust the jumpers, starting from the middle position, if needed.

With these simple steps, your Analog Signal PCB will be clean, adjusted, and ready for experiments.

# Versioning

Authors | Version | Date | Comment
L. Durieux | V1.0 | 23.09.25 | Document first release
A. Barbelivien M. MAJCHRzAK | | 01.11.25 | Proofreading

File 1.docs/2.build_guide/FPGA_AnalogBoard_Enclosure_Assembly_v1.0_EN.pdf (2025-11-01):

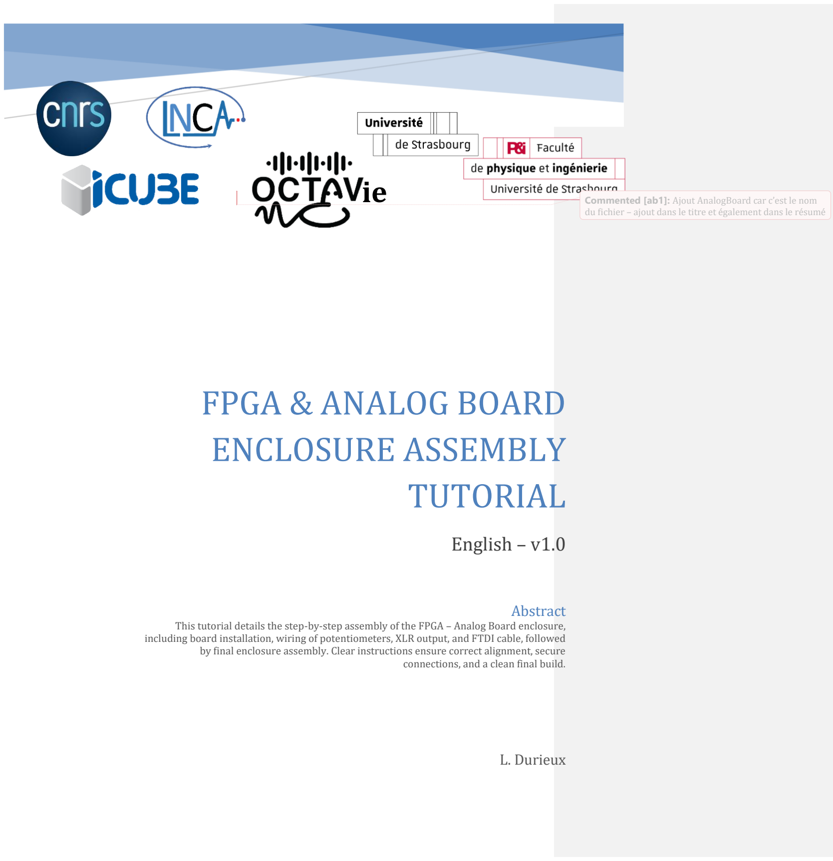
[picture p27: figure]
FPGA & ANALOG BOARD ENCLOSURE ASSEMBLY TUTORIAL; English – v1.0; L. Durieux; Abstract; connections, and a clean final build.

This tutorial details the step-by-step assembly of the FPGA – Analog Board enclosure, including board installation, wiring of potentiometers, XLR output, and FTDI cable, followed by final enclosure assembly. Clear instructions ensure correct alignment, secure

ie | Commented [ab1]: Ajout AnalogBoard car c’est le nom
| du fichier – ajout dans le titre et également dans le résumé

### Table of Contents

Commented [ab2]: Attention le point 3-4 n’existe pas

### Section 1 — FPGA Board

### 1.1 Remove Factory Standoffs and Plastic Cover

Start by unscrewing the default metal standoffs and removing any plastic film or protective elements on top of the FPGA board. These are not compatible with our custom 3D-printed enclosure and analog signal board.

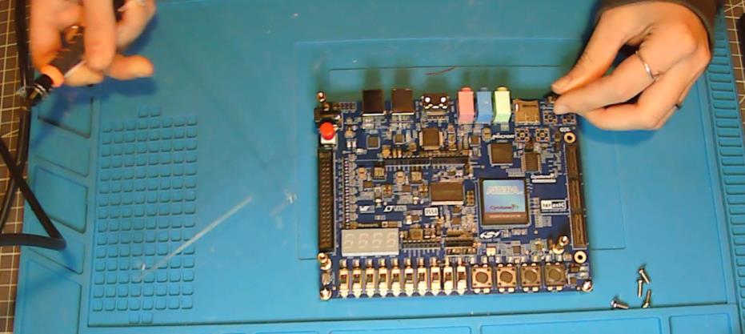
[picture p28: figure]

### 1.2 Reuse 4 Standoffs Under the Board

Keep only four of the original standoffs and screw them underneath the board in each corner. All other standoffs can be discarded or stored away.

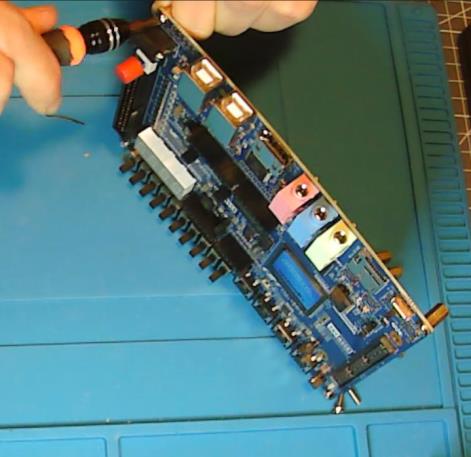
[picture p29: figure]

### 1.3 Insert the FPGA into the 3D-Printed Base

Carefully position the FPGA board into the 3D-printed enclosure. Make sure that the USB ports and power connector align properly with the cutouts in the enclosure walls.

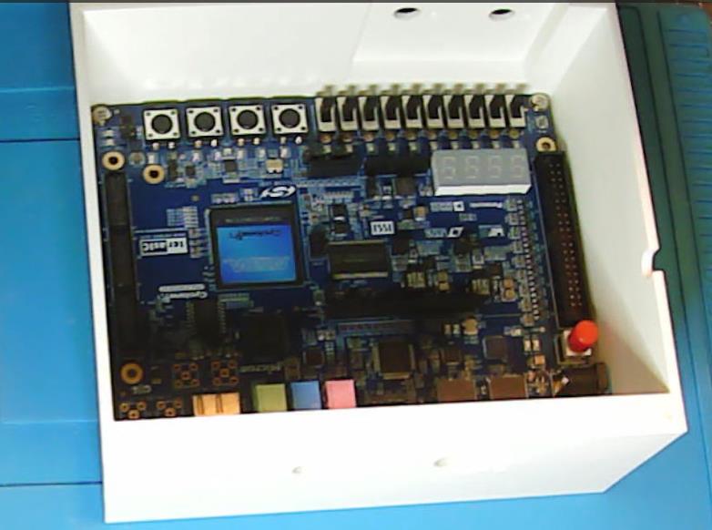
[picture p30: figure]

### 1.4 Screw the Board into Place

Use M3x5 screws to attach the board to the 3D-printed base via the four standoffs. Ensure the board sits flat and firm inside the enclosure.

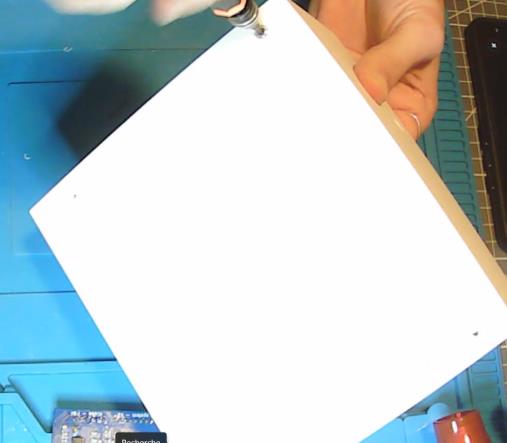
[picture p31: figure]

### 1.5 Connect the Analog Daughterboard

Install the analog PCB onto the FPGA by aligning the headers. The board fits in only one orientation. Press it down firmly until all pins are seated.

### Section 2 — Potentiometers

### 2.1 Cut and Prepare Wires

Cut 6 wires total: 2 orange (signal), 4 white (power and ground). For the upper channel (channel 1), use 15 cm wires. For the lower one (channel 2), 10 cm wires are enough.

### 2.2 Strip and Pre-Tin the Wires

Strip approximately 1 cm of insulation from one end of each wire for soldering. Optionally tin the ends with a bit of solder for ease of assembly.

### 2.3 Solder Wires to Potentiometers

Thread each wire through the small holes in the potentiometer terminals. Wrap the exposed copper around the pin and solder it. The recommended order from left to right (facing the shaft) is: orange (input signal), white (output signal), white (output signal).

Commented [ab3]: Faut-il mettre cette photo ici car dans la section 2, il y a une partie où la pièce analog BCP est utilisée? Ne faut-il pas plutôt la mettre en section 5 en premier point ?

Commented [ld4R3]: Je trouve que la photo est bien dans la partie “connect the board”. Du coup, je pense que c’est mieux ici. La première partie de la 5 c’est connecte les JSTs et comme on en parle tout le long je pense que la photo n’est pas nécessaire, si ?

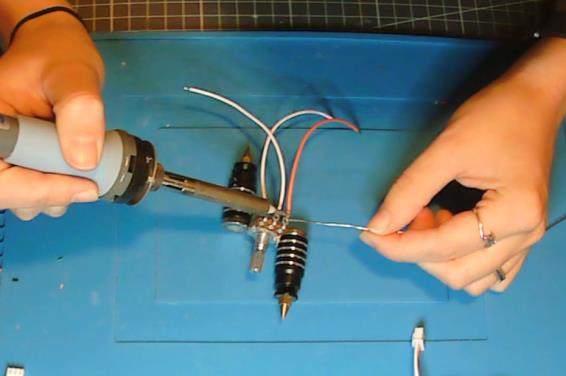
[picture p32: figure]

### 2.4 Crimp and Insert JST Connectors

On the other end of each wire, strip 2–3 mm and crimp JST contacts. Insert the contacts into a 3-pin JST housing. Make sure the orange signal wire goes to the correct slot (typically pin 1). The final order can be seen in the next part. Use heat shrink tubing if desired to bundle the wires.

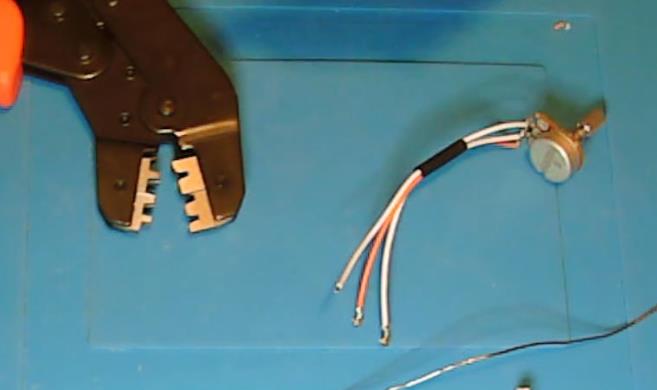
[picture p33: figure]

### 2.5 Connect to Analog Board Headers

Plug each 3-pin JST connector into the matching header on the analog board. Ensure the upper potentiometer (15 cm wires) connects to the upper header.

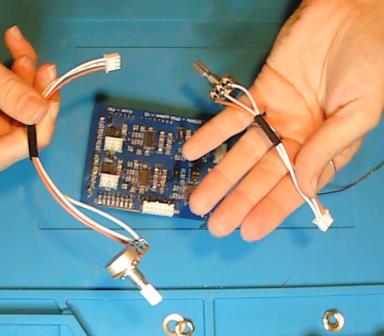
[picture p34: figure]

### Section 3 — XLR Output

### 3.1 Use a 3-Pin XLR Male Connector

We use a standard 3-pin XLR male connector to carry the analog output. Prepare three wires of about 20 cm each in distinct colors (e.g., red, black, green).

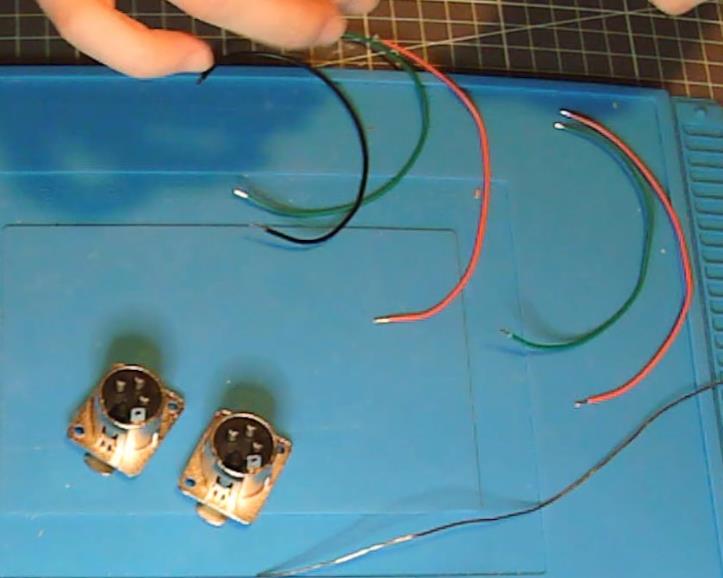
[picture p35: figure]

### 3.2 Solder Wires to the XLR Pins

Solder the wires to the XLR pins according to the standard: Pin 1 = GND, Pin 2 = Signal, Pin 3 = VDD. Make sure your analog board output header matches this logic. Be careful to follow the order of the cabling since the microphone is not protected. A wrong cabling could lead to its destruction.

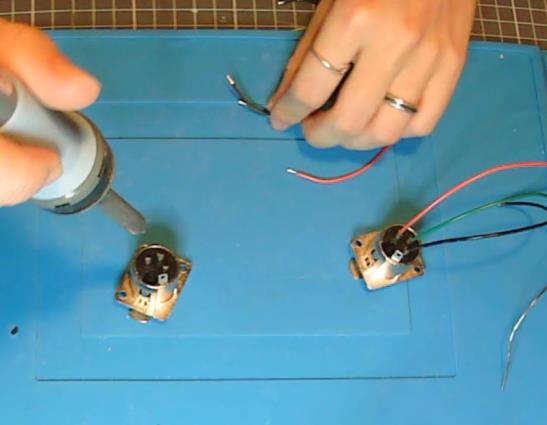
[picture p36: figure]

### 3.3 Mount the XLR Connector in the Rear Panel

Connect the XLR Wires to the Analog Board

Attach the wires to the analog board output header via a 3-pin JST. Double-check signal integrity and pin order.

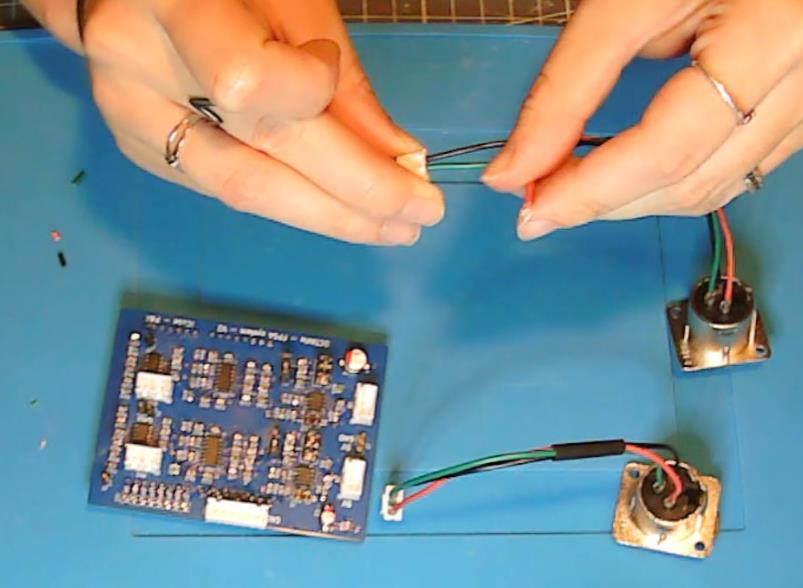
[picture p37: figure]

### Section 4 — FTDI Cable

### 4.1 Cut and Strip the FTDI Cable

Cut the FTDI cable to desired length (nearer of the header as possible to keep a maximum length is a comfortable solution). Strip all six wires.

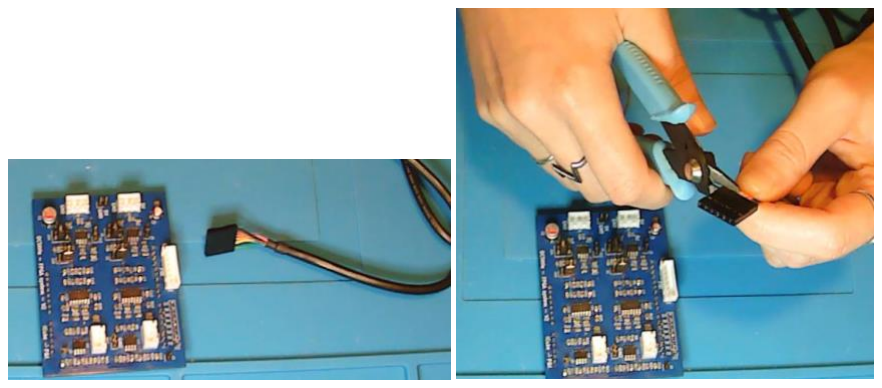
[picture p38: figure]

### 4.2 Crimp Contacts and Insert into Keyed Connector

Crimp each wire into a JST contact and insert them into a 6-pin keyed JST housing in the following order starting from GND, written on the PCB board: Black, Brown, Red, Orange, Yellow, Green.

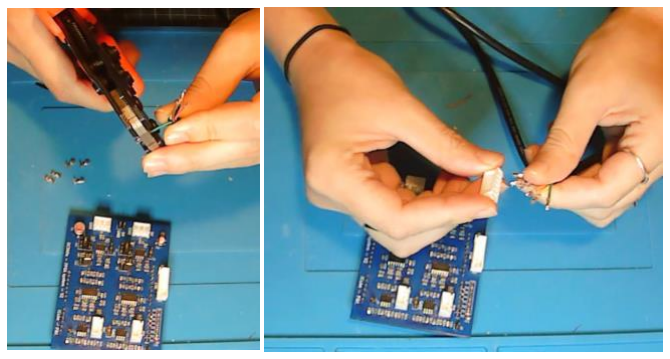
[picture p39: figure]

### 4.3 Plug into J12 Header on Analog Board

Insert the keyed connector into J12 on the analog board. The notch ensures correct polarity.

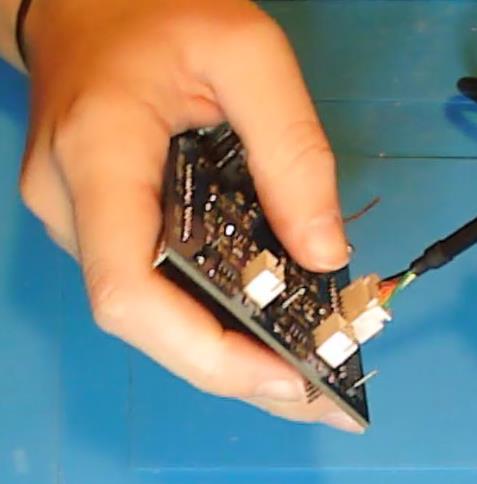
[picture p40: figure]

### Section 5 — Final Assembly

### 5.1 Insert All Connectors and Cables Neatly

Make sure all JST cables are connected securely. Route cables neatly so that they do not interfere with the enclosure lid.

### 5.2 Attach Front and Rear Panels

Screw the front and rear panels into the 3D-printed base. Align all cutouts and components properly.

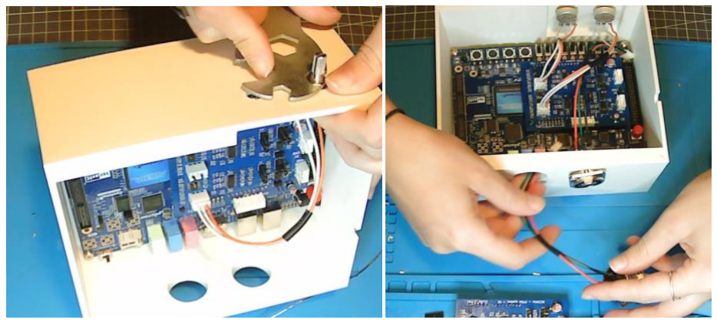
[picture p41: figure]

### 5.3 Add the Top Lid and Knobs

Use the M3x5 screws to secure the top lid. Install plastic caps on the potentiometer shafts and mark the channels if needed.

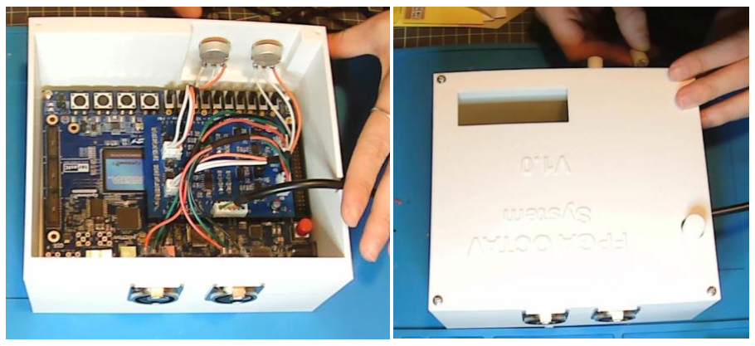
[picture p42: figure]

### License Information

Hardware license: CERN Open Hardware License v2 (Strongly Reciprocal – OHL-S).

Software license: GNU General Public License v3 (GPLv3), ensuring that all modifications remain open-source.

Documentation license: Creative Commons Attribution-ShareAlike 4.0 International (CC-BY-SA 4.0).

### Versioning

AUTHORS | VERSION DATE | COMMENT
L. DURIEUX | V1.0 | 26.09.25 | Document first release
A. BARBELIVIEN
M. MAJCHRZAK
| V1.1 | 01.11.25 | Proofreading

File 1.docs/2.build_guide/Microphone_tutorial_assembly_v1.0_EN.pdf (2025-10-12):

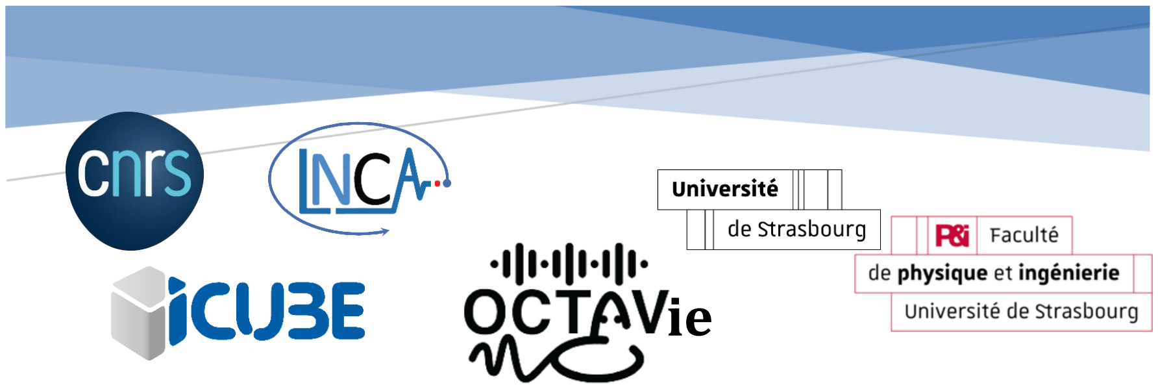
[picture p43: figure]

# MICROPHONE TUTORIAL ASSEMBLY

## English – v1.0

### L. Durieux

### Abstract

This guide details the complete assembly process of the OCTAVie open-source microphone, from PCB preparation to final enclosure mounting. It provides clear, reproducible instructions for soldering, wiring, and testing the system. All related design files and resources are available in the OCTAVie Zenodo repository.

### Table of Contents

### 1. Introduction

This tutorial provides detailed step-by-step instructions for assembling the OCTAVie microphone module. It guides users through the complete process from unpacking the PCB to the final enclosure assembly. All the full CAD models, PCB design files, and supporting materials can be found in the Zenodo repository.

### 2. Required Materials and Tools

Before beginning the assembly, prepare the following materials and tools:

Microphone PCB (v1.0, from JLCPCB)
3D-printed enclosure (microphone box and lid)
XLR connector (male)
JST-PH female connector (3-pin)
3-pin cable shielded (approximately 2 m) Wire stripper and precision pliers Soldering iron
Solder wire (0.5 mm)
Small screwdriver
Multimeter for continuity testing

### 3. Step-by-Step Assembly

### Step 1 — Separate the PCB

When the microphone PCB arrives from JLCPCB, it usually comes attached to a panel with Vcuts along the edges. Carefully break the board free along these cuts to obtain the individual PCB.

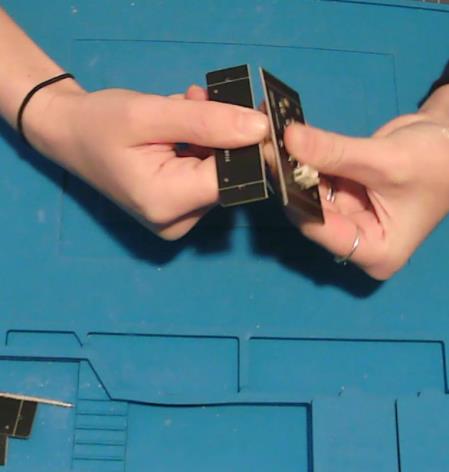
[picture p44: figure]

### Step 2 — Place the PCB in the 3D-Printed Enclosure

Insert the PCB into the dedicated 3D-printed base. Make sure that the microphone opening is perfectly aligned with the hole in the enclosure. Secure the PCB using small M2 screws at

each corner.

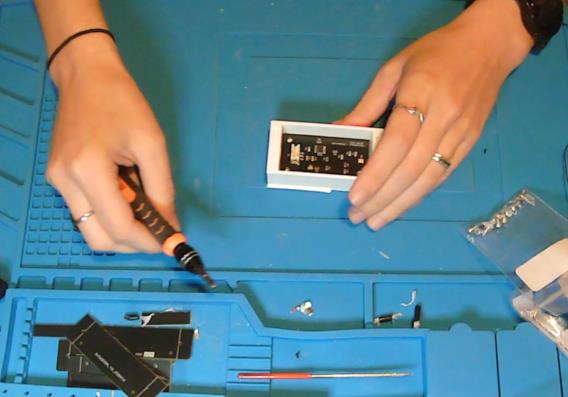
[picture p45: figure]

### Step 3 — Prepare the XLR Cable

Cut approximately 2 meters of the XLR cable and strip around 3 cm of the outer insulation. Expose the three internal wires (red, white, and bare shield) and strip about 2–3 mm of each conductor.

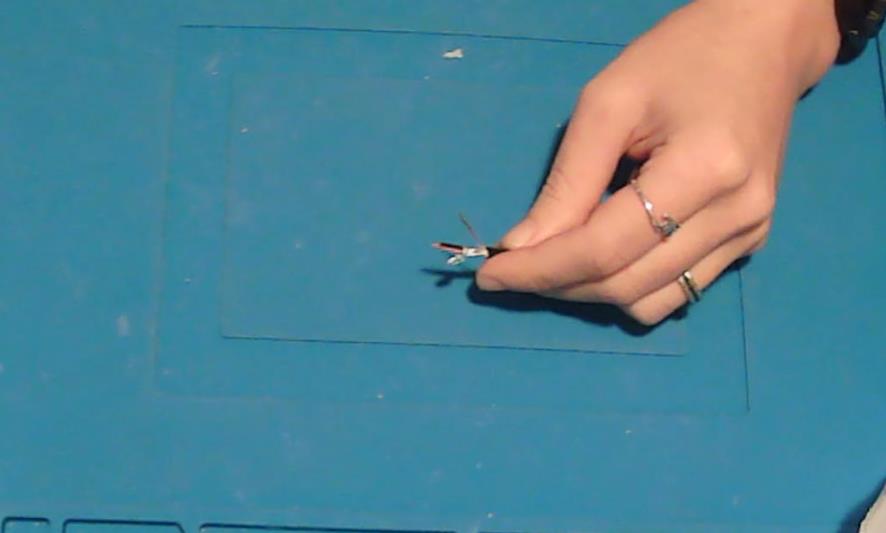
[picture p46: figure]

### Step 4 — Solder the XLR Connector

Looking at the male XLR connector from the front (forming a 'V' shape), solder the wires as follows:
- Left pin → GND (shield wire)
- Middle pin (down) → Signal
- Right pin → Power (red wire)
After soldering, reassemble the connector housing and ensure all mechanical parts are

properly secured.

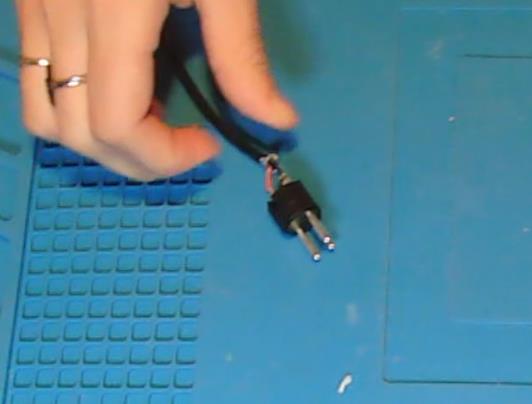
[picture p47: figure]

Using a multimeter, check the continuity between each pin of the XLR connector and the other end of the cable. Ensure there are no short circuits or open connections. This step guarantees reliable signal and power delivery.

### Step 5 — XLR assembly

Assemble de XRL connector

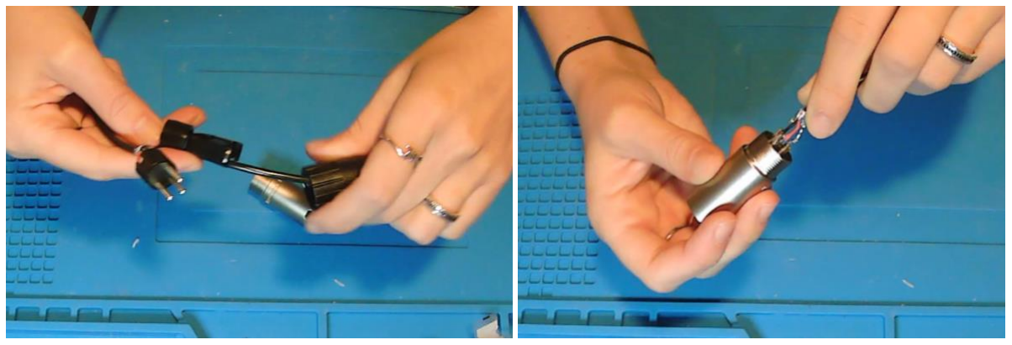
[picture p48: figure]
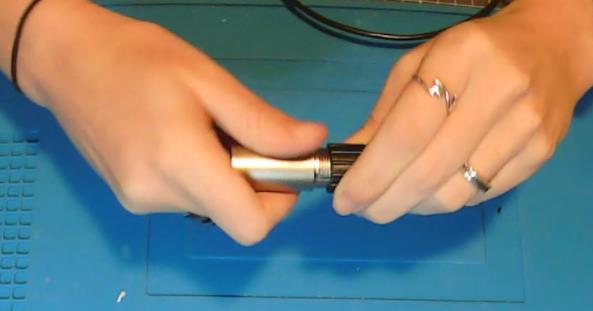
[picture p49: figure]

### Step 6 — Crimp the JST Connectors

At the other end of the cable, crimp the three wires with JST-PH terminals and insert them into a 3-pin JST-PH female connector. The pinout must match the corresponding connector on the microphone PCB:
- Pin 1 → Power (red wire)

- Pin 2 → GND (shield wire)
- Pin 3 → Signal

### Step 7 — Connect and Close the Enclosure

Insert the cable through the side opening of the 3D-printed box and plug the JST connector into the microphone PCB. Ensure the cable is properly routed without tension. Then, close the lid of the enclosure and secure it with four screws.

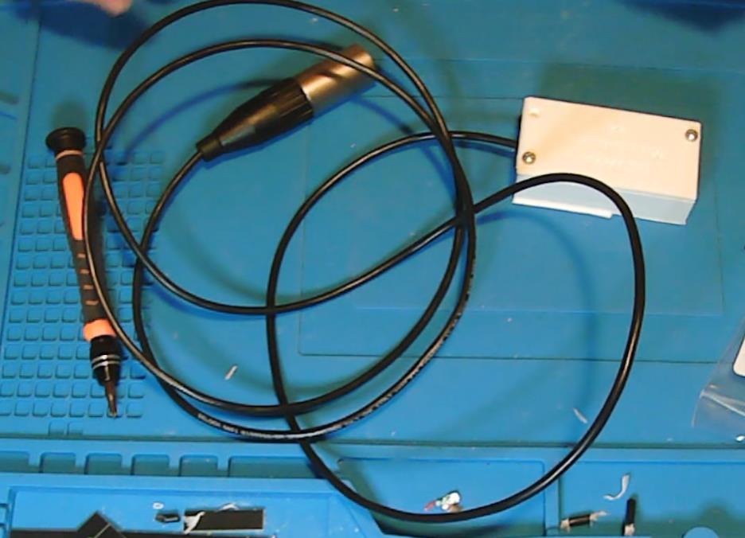
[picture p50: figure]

### Step 8 — Final Verification

Before using the microphone, perform a quick functional test by connecting it to the acquisition unit via the XLR connector. Check that the signal is detected correctly and that no noise or instability appears.
If everything is working properly, the microphone assembly is complete.

### License Information

Hardware license: CERN Open Hardware License v2 (Strongly Reciprocal – OHL-S).

Software license: GNU General Public License v3 (GPLv3), ensuring that all modifications remain open-source.

Documentation license: Creative Commons Attribution-ShareAlike 4.0 International (CC-BY-SA 4.0).

### Versioning

AUTHORS | VERSION | DATE | COMMENT
L. DURIEUX | V1.0 | 12.10.2025 | Document first release

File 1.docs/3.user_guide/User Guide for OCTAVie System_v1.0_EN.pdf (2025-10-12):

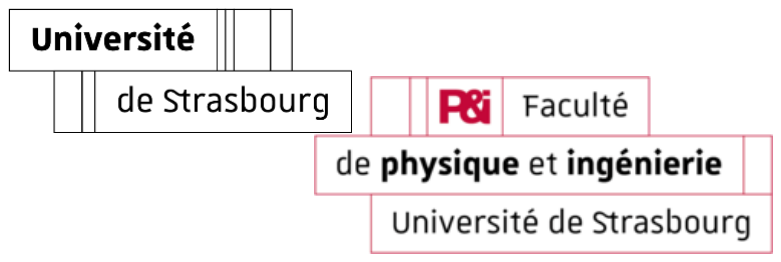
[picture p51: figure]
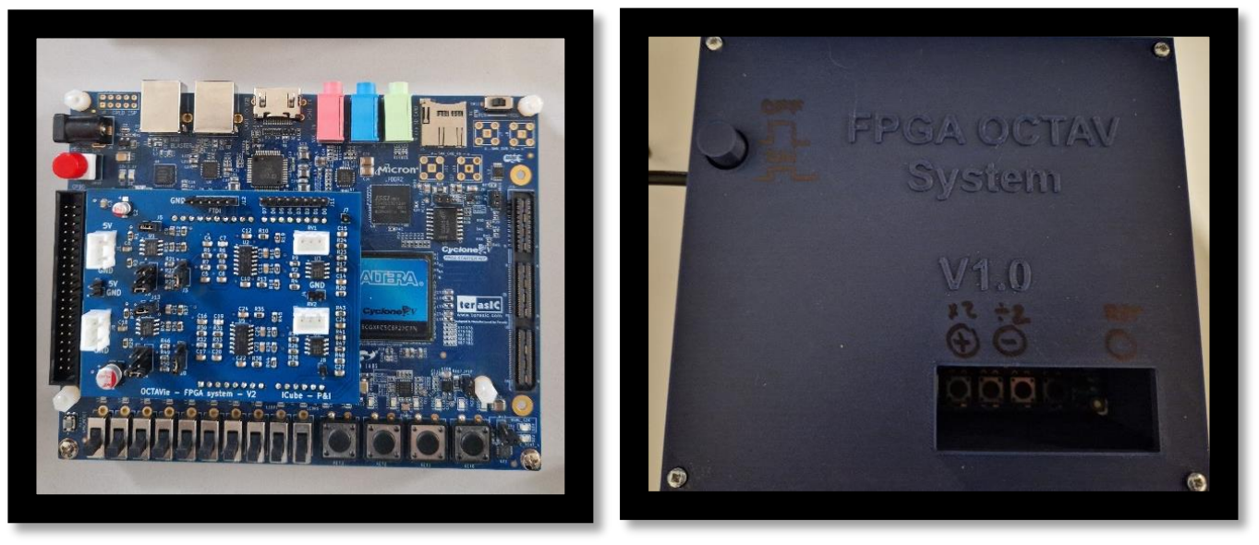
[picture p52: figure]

1 | P a g e

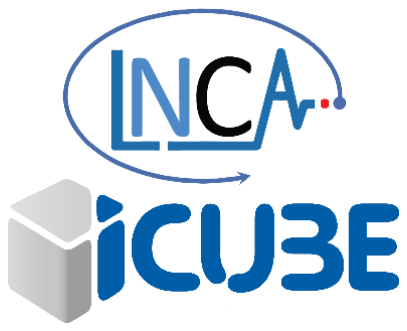
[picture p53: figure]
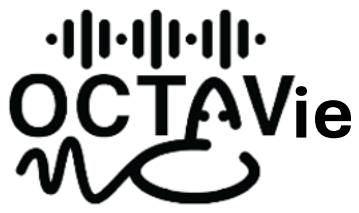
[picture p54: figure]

# User Guide for OCTAV system

## Hardware and software use guide

### TABLE OF CONTENTS

### . INTRODUCTION

The near-real-time sonogram display system is an innovative tool designed to record, process, and visualize rodent vocalizations in the ultrasonic frequency range, which is beyond human hearing. This system is part of the larger OCTAVie project, aiming to provide an open-source, low-cost solution for studying animal communication, particularly in neuroscience research. It enables real-time processing of ultrasonic signals, significantly reducing the need for extensive post-recording processing by directly producing spectrograms that map vocalizations across time, frequency, and amplitude.
The system integrates various hardware and software components to deliver efficient signal processing and data management. It eliminates the bottleneck of excessive data storage and time-consuming signal analysis, paving the way for more accessible research in animal behavior. Explain hardware and software requirements.
The first prototype successfully integrates an ultrasonic microphone, analog anti-aliasing filters, an FPGA-based FFT processing unit, and a computer interface for data transfer. It achieves real-time conversion of rodent vocalizations into visual spectrograms, with the FFT implemented on the Cyclone V GX FPGA development board. This prototype also features a C-based software application to capture and save FFT frames received via serial communication (Real time Graphic Interface Interface).
However, several aspects are still under development, including:
- Optimal Power Resolution: Fine-tuning the power calculation step to determine the best 12-bit representation of the 24-bit FFT output.
- Enhanced Data Transfer Methods: Exploring alternative high-speed communication protocols to improve data throughput and system scalability for multi-channel inputs. ________________________________________

## UNBOXINGANDINSTALLATION

I. SYSTEM COMPONENTS
The system is composed of several parts: The FPGA box, the power cable and the microphone. The different parts will be detailed in this part.

### 1. FPGA Box

The FPGA box (Figure 1) includes several internal components: the FPGA development board, the analog filter that conditions the signal, and the FTDI cable needed to connect to the computer.

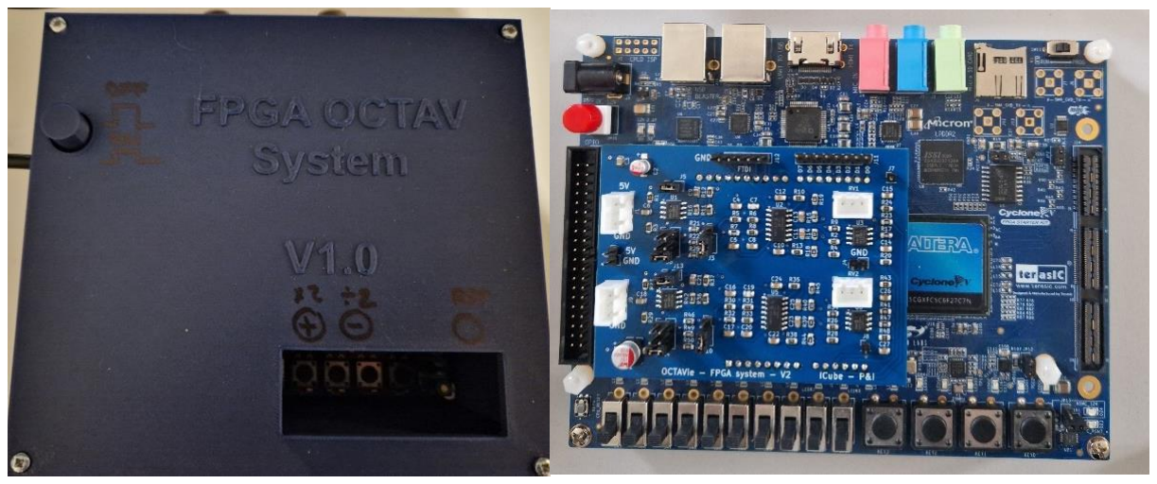
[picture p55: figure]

Figure 1:On the left, FPGA box V1.0 containing the circuit shown on the right.
Note: The current version of the box must remain upright since the FPGA board is not securely fixed within the box.

Description of the FPGA box
The FPGA box features:
- Front: Two rotary knobs to adjust gain (Figure 2-A)
- Left Side: USB cable and power plug (Figure 2-B)
- Back: Two XLR female connectors (Figure 2-C)
- Top: Start button on the top left, with a small access window for the development board buttons (Figure 2-D)

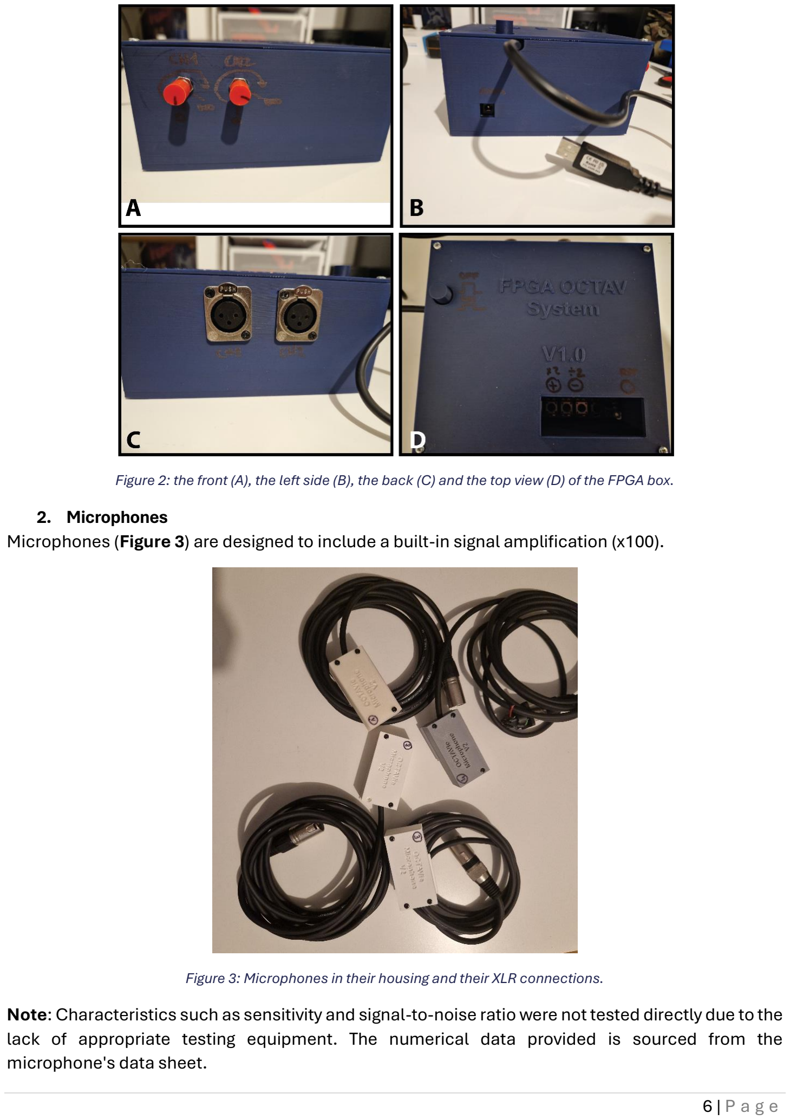
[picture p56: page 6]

Figure 2: the front (A), the left side (B), the back (C) and the top view (D) of the FPGA box.

### 2. Microphones

Microphones (Figure 3) are designed to include a built-in signal amplification (x100).

Figure 3: Microphones in their housing and their XLR connections.
Note: Characteristics such as sensitivity and signal-to-noise ratio were not tested directly due to the lack of appropriate testing equipment. The numerical data provided is sourced from the microphone's data sheet.

Microphones can be mounted on adjustable supports (Figure 4), allowing them to be easily oriented toward the animal cage.

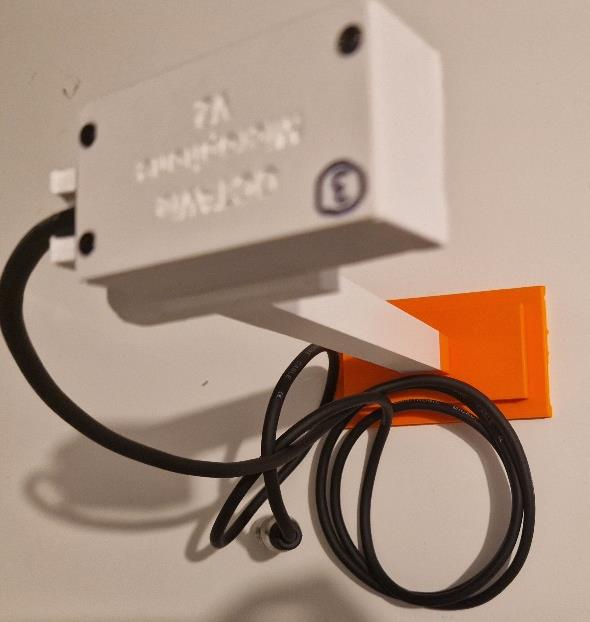
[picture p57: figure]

Figure 4: Microphone and its support.

### 3. Power connection

The FPGA development board is accompanied by a power cable. Kindly ensure that only the provided cable is used.

II. SOFTWARE INSTALLATION

### 1. Full installation

The procedure for installing the software will be included in the manual shortly.

### 2. Update the software

Coming soon.
________________________________________

## STARTUP

I. CONNECT COMPONENTS
Connect the power supply to the left side of the FPGA box (Figure 5) and plug the XLR microphone into the back. From the rear view, channel 1 is on the left and channel 2 is on the right (labeled on the box – Figure 6).

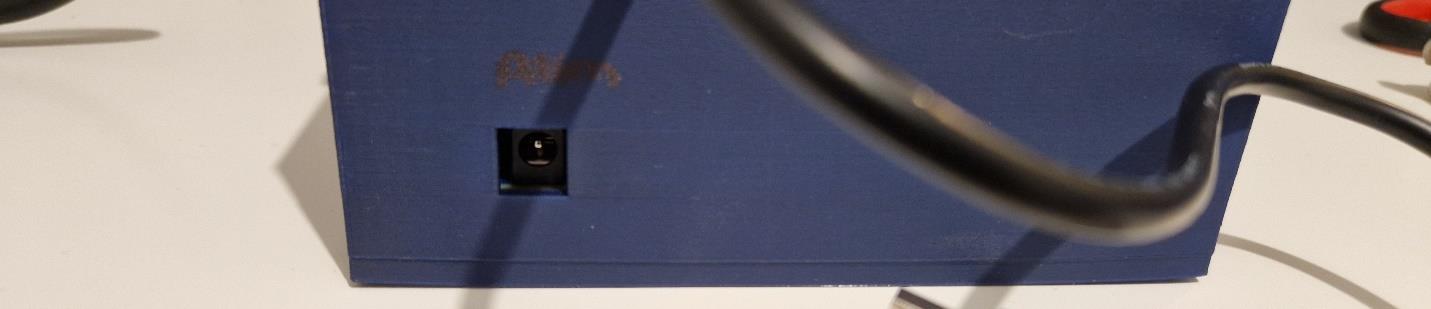
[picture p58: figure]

Figure 5: Left side of the box with the hole to plug the power cable.

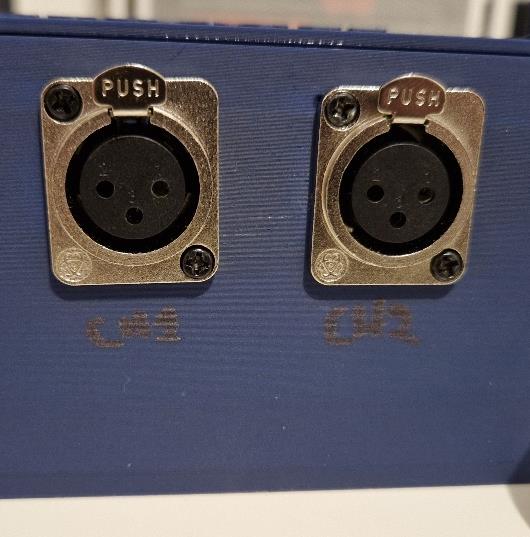
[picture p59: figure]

Figure 6: The deux XLR plugs to connect the microphones.
Please be advised that only the difference between the two microphones will be recorded. If you wish, you can connect with a single microphone. In this instance, the recorded signal will emanate solely from the connected microphone, without any subtraction applied.
Connect the USB cable from the left side of the FPGA box to your computer. After completing this step, you can proceed to power on the device by pressing the button located on the top (refer to Figure 7). The device is powered on when the button is in the down position and powered off when the button is in the up position.

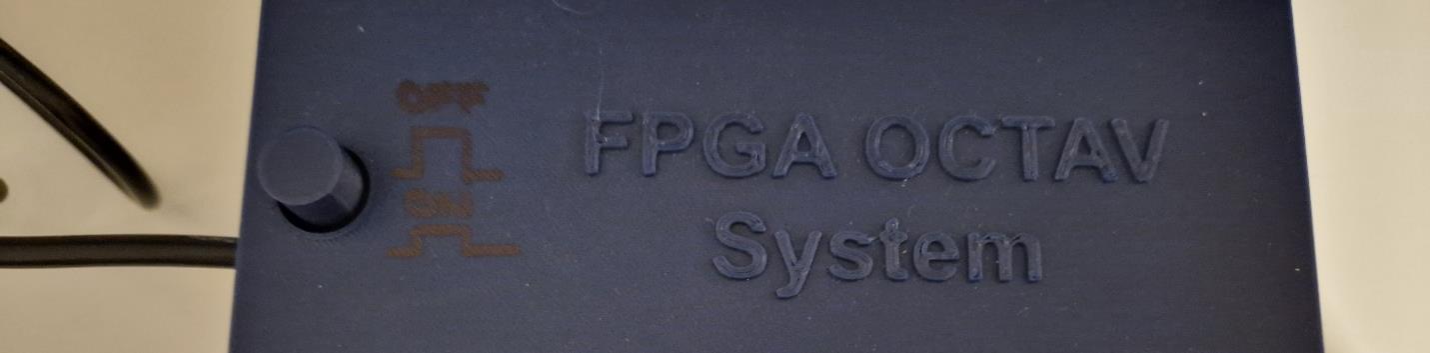
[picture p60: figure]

Figure 7: The top view of the FPGA box with the power button located on the left side of the image.
Upon initialization of the FPGA, an LED will be observable blinking through the window located at the top of the enclosure designated for button access.

II. STARTING AND USING THE SOFTWARE
Please note that this tutorial is specifically designed for Windows users. Although the software is compatible with Linux, guidelines for Linux users will be provided at a later date.

### 1. Starting the soft

Double-click on the OCTAVie icon located on the desktop.

A black command window will open (Figure 8) that displays OCTAVie information messages.


Figure 8: Command window where OCTAVie software can display information.
After a few seconds, the GUI OCTAVie will open (Figure 9). Please allow time for the interface to fully launch.


Figure 9: OCTAVie GUI.

### 2. Configuration of the serial port (COM port)

Right click on the Windows start button:

Then select "device manager" (or "gestionnaire de périphérique" in French - Figure 10).


Figure 10: Windows right click menu.
A window will open displaying all the peripherals of the computer. Please note that a small window may appear indicating that modifications are restricted to administrators (read-only). Disregard this message and click "OK".
Select the small arrow next to "Ports (COM and LPT)" as illustrated in Figure 11.


Figure 11: Device manager menu.
Several lines may appear below the menu. Locate the one starting with "USB Serial Port". Please enter the same number associated with the port into the Com port field in the graphical interface (Figure 12). If no lines match, ensure that the device is powered on and the USB is properly connected. Should these conditions be met and the issue persists, try using an alternative USB port on your computer. If this still does not resolve the problem, please contact us using the information provided at the end of this document. If multiple lines correspond to "USB Serial Port", unplug the USB from the device and reconnect it. The line that disappears and reappears will be the correct one.


Figure 12 : Indication of the com port to OCTAVie software.

At this stage, please change the name of the file in the “Output file” field (Figure 13). This is the name of the file where the data will be saved. You may choose any name you prefer, but ensure it ends with “.csv.” For optimal processing, avoid using special characters, except for the underscore (“_”). Example: manip_XXX_ratXXX_250120.csv
Important: If you neglect to change the name and a file with that name already exists, the existing data will be overwritten.
Note: Windows users should not modify the “Com path.”


Figure 13: OCTAVie interface with an example of the file name.

3. Launching the visualization and recording.
Click the Start button (Figure 13) in OCTAVie to visualize the data. Note that this action only visualizes the data and does not record it.


Figure 14: Start button location on OCTAVie interface.
On the command terminal, you should see this message:

If the message does not display, it likely means that you have not configured the com port correctly. Please refer to the earlier section for guidance. Another possibility is that the com port is already in use, as only one software can access the com port at a time. This possibility is less common, but you should ensure that OCTAVie is not opened more than once.
To check data reception, you can snap your fingers in front of the microphone, which should produce a response on the graph as shown in Figure 15. Alternatively, you can strike two metal objects together, and this should generate a response similar to the one displayed in Figure 16. Note that both examples also show large responses across all frequencies, which are transmission errors. Be aware of their shape to avoid confusing them with actual responses.


Figure 15 : Spectrogram with the frequency response to clapping fingers in front of the microphone. The blue circles represent the real response, and the red lines represent the transmission errors..


Figure 16: Spectrogram with the response of clapping two metal objects together (weakly), highlighted with the blue circle. The red lines represent the transmission errors
At this stage, it is essential to adjust the amplitude of the signal to ensure that it is sufficient to capture rodent vocalizations accurately. Please refer to the next chapter for information on the available options within the system to manage the recording amplitude (the sensitivity).
Once the settings have been configured satisfactorily, you may proceed with initiating the data recording.
To start the data recording, please left click on the “Record” button in the OCTAVie interface window, as illustrated in Figure 17.


Figure 17: Location of the Record button in OCTAVie interface.
In the command terminal, you should see appear the following message:

Once the recording has started, to stop it, please left click on the "Stop" button in the OCTAVie interface window.
The following message should appear in the command terminal to confirm the completion of the recording and display.

Important: Set the COM port before starting ("Start" button) and write down the name of the file before recording ("Record" button). If the COM port is not valid, the software will not be able to read the data. Additionally, if the file name already exists in the folder containing the recorded data, it will be erased without warning after clicking the "Record" button. Ensure that the "Start" button is clicked and data is displayed BEFORE clicking the "Record" button. Otherwise, the CSV file created will be empty.
Advice: COM port -> file name -> START -> RECORD (if needed) -> STOP -> file name -> START -> RECORD (if needed) -> STOP. Note that the COM port only needs to be set when opening the software. If you do not close it, you do not need to set the COM port again.

### 4. Opening the data into Excel

You will find your recorded data in the same folder as the executable (.exe). For example: Documents => Octavie_soft
Important: Do not open the file during recording.
Open this file in Excel as usual. The rows represent time points with a resolution of 2.56 ms, and the columns represent frequencies with a resolution of 390Hz.
Be aware that if the file is too large, Excel may crash. It is advisable not to open a document with more than 40 minutes (based on calculation) of recording, which is equivalent to one million rows in Excel.
You are now ready to record your data. The next chapter covers the device settings options.

________________________________________

## DEVICE SETTING OPTIONS

There are two primary methods to adjust the amplitude of the recorded signal within the system. Additionally, it is possible to directly adapt the filter (derivator) parameters on the PCB. However, this option should only be utilized by individuals who are proficient with PCBs and jumper settings. The first section of this chapter will explain how to configure the device using the user-friendly rotary and push buttons. The second section will provide detailed instructions on the jumper configurations.

I. ADJUST BASIC SETTINGS (INPUTS/OUTPUTS).
In this section, you will learn how to set the desired amplitude of the signal. Please note that the microphone provides a fixed amplification of 100.
Vocabulary Note: The gain refers to the amount by which the obtained signal is increased compared to the original signal. In this specific context, it indicates the extent to which the amplitude of the signal generated by the microphone is enhanced.
The rotary knobs (Figure 18):


Figure 18: Rotating knobs to set up the amplification gain.
You can set the amplitude from just under 1 to 100. Each microphone's gain is adjustable using its respective rotative button (left for the first channel, right for the second). Turn clockwise to increase gain and counterclockwise to decrease it.
Warning: The rotative button is very sensitive.
Development board buttons (Figure 19):


Figure 19: Push button located in the opening of the FPGA Box. The red button is functional, while the blue button is not programmed (not functional).
The FPGA development board is equipped with four push buttons, accessible through an open window on the top of the box. On the far right (when looking at the front of the box), there is a reset button. The two buttons on the left are used to adjust the gain as needed; the leftmost button is labeled “+” and the second button is labeled “-”.
- Reset Button: This button resets the board, restarting the processes running from the beginning. If you encounter unusual FFT results, pressing this button may help by reinitializing the board's memory and restarting all operations.
- “+” Button: Increases the signal amplitude by a factor of 2.
- “–” Button: Decreases the signal amplitude by a factor of 2.
*Note*: The “+” and “–” buttons have scale limitations. You cannot press the “+” or “-” buttons more than a defined number of times after starting the FPGA. The FPGA always starts from the same point of the scale and does not save the previous state. Therefore, it is advisable to note down the state before turning off the FPGA and restore it when starting a new experiment.


Figure 20: Scale of the amplification given by the number of clicks on the button "+" or "-".

II. ADVANCED SETTINGS (JUMPERS CONFIGURATIONS)
This part is not written for the moment. Please, contact me if you need to know more about that ________________________________________

## TROUBLESHOOTING

This section will address issues as they arise and document the main solutions.

I. HARDWARE ISSUES
If the board does not start, please first check that the power plug is correctly connected at both ends. If the board starts but the LED is not blinking, it indicates an issue with the board's firmware. You will need to re-upload the bitstream file.

II. SOFTWARE ERRORS
Occasionally, we encounter an issue with GTK (C libraries that create the graphical interface) where the image stops displaying for a few seconds. During this time, the FFT graphics will appear white. This issue is likely due to the GTK libraries and is beyond our control. However, it does not affect the recording process. The data will continue to be safely recorded even during this bug. You just need to wait for the GTK issue to resolve.

III. CONNECTION ISSUES

### 1. Transmission errors

The primary issue involves transmission errors, which can sometimes be more significant than others. Our current method of transmitting data is simple but not highly secure. It is common to experience one error per millions of octets transmitted, which aligns with our observations. Therefore, a straightforward solution to correct these errors is not feasible. We are considering ways to reduce these errors.

### 2. Com port

If the software indicates that the COM port is not accessible, please verify that the number being used is correct. To do this, follow the steps in the relevant chapter. Once in the "Device Manager," you can plug and unplug the USB cable to ensure that the COM port disappears when unplugged and reappears when replugged. If this does not resolve the issue, check if the COM path has changed (for Windows users). If in doubt, close the software and reopen it.

If help is needed, please contact us.

________________________________________

## SAFETY ANDMAINTENANCE

### VERSIONING

AUTHORS | VERSION DATE | COMMENT
L. DURIEUX | V0.1 | 27.01.25 | Document first release
L. DURIEUX | V1.0 | 04.10.2025 | Formatting

________________________________________

## TECHNICAL SPECIFICATIONS

In this part, the main characteristics of the different parts of the system (V1.0)

I. FPGADEVELOPMENT BOARD
The details on FPGA are provided in Table 1. Please note that the current version of the box should be kept on the right side, as the FPGA board is not securely fixed within the box.

Table 1 FPGA Development board characteristics.
Characteristic | Description
FPGA Model Development Board | Cyclone V GX Starter Kit.
FPGA | Cyclone V GX 5CGXFC5C6F27C7N
ADC | LTC2308 (12-bit, 500 ksps).
Main function | Real-time FFT processing and data transfer.
Connections | Microphone (XLR female), power (5 V), FTDI cable for USB transfer.

II. CONDITIONING CIRCUIT
The characteristics of the conditioning circuit are in the Table 2:

Table 2: Characteristic of the conditioning circuit.
Characteristic | Description
Filter Type | Sallen-Key (bandpass filter).
Sallen-Key (bandpass filter). | High-pass: 10 kHz; Low-pass: 100 kHz.
Derivator | Settable
Operational Amplifier | MCP602X (10 MHz gain-bandwidth product).
Adjustable Gain | Adjustable via a potentiometer. (from ~1 to ~100)
Main Function | Anti-aliasing filtering and signal amplification before digital conversion.

III. MICROPHONES
The characteristics are details in the Table 3 below.

Table 3: Main characteristics of the microphones.
Characteristic | Description
Model | Knowles SPU0410LR5H-QB.
Technology | Piezoelectric MEMS microphone.
Frequency Range | 1kHz to 100KHz
Sensitivity | -38 dBV/Pa at 1 kHz
Signal-to-Noise Ratio | 63 dB(A).

Connectivity | XLR males
Main Function | Detect ultrasonic sounds up to ~ 100 kHz.

### IV. FTDICABLE

FDTI cable allows us to bring the data from the FPGA ship to the computer. It translates the UART signal to USB protocol. The characteristics are listed in the Table 4.

Table 4: FTDI Cable characteristics.
Characteristic | Description
Model | TTL-232R-3V3.
Connection Type | UART (FPGA) to USB (computer) conversion.
Baud Rate | 3 Mbps
Main Function | Fast and reliable transfer of FFT data to the visualization software on a PC.

________________________________________

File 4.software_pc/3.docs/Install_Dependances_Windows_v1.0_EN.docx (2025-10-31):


ie

L. Durieux

Abstract

This document explains how to install and configure the OCTAVie software on a Windows system. It details the required dependencies and setup steps to ensure proper execution of the graphical interface and communication with the FPGA. The procedure includes installing necessary libraries and drivers, as well as configuring the environment for smooth operation. Following this guide allows users to easily reproduce a functional setup and run the OCTAVie software reliably under Windows.

Install Dependances Windows

English – v1.0

# Introduction

This document explains how to install the dependencies required to run or rebuild the OCTAVie PC software on Windows.

There are two cases:

- Case A — Run-only (prebuilt executable, Windows x64) You only want to run the program provided as a .exe (no source code changes). 👉 Install GTK4 runtime for Windows x64 only.
- Case B — Develop & Rebuild (from sources) You want to edit the code and recompile using the provided Makefile. 👉 Install a full MSYS2/MinGW-w64 toolchain + GTK4 dev packages.

# Case A — Run the prebuilt executable (Windows x64)

Goal: run OCTAVie.exe without compiling anything.

⚠️ For GTK4 on Windows, there isn’t a single “official GTK4 runtime installer” like there was for GTK2/3. The recommended way for end-users is to install the MSYS2-based GTK4 runtime (which provides the GTK4 DLLs), or—alternatively—you bundle the DLLs yourself with the app. Below uses the MSYS2 runtime, which is simple and reliable. The GTK Team+1 (https://www.gtk.org/docs/installations/windows?utm_source=chatgpt.com)

## A1) Install the GTK4 runtime via MSYS2 (recommended)

1. Download MSYS2 (64-bit) Open the official MSYS2 site and download the x86_64 installer (“msys2-x86_64-….exe”). packages.msys2.org (https://packages.msys2.org/package/mingw-w64-x86_64-gtk4?utm_source=chatgpt.com)
2. Install with defaults
  - Run the installer, keep default path C:\msys64.
  - Finish and launch “MSYS2 MinGW64” from the Start Menu (not “MSYS” and not “UCRT64”).
3. Update the package database In the MSYS2 MinGW64 terminal, run:

pacman -Syu

if it asks to close/reopen, do so, then:

pacman -Su

4. Install the GTK4 runtime package (x64) Still in MinGW64:

pacman -S mingw-w64-x86_64-gtk4

This pulls the GTK 4.x DLLs and dependencies for 64-bit Windows. packages.msys2.org (https://packages.msys2.org/package/mingw-w64-x86_64-gtk4?utm_source=chatgpt.com)

5. (Option A) Add the GTK/MinGW64 bin folder to PATH (so Explorer can find DLLs)
  - Windows: open System Properties → Environment Variables → System variables → Path → Edit.
  - Add:
  - C:\msys64\mingw64\bin
  - Click OK on all dialogs.

OR

(Option B) Run from the MinGW64 shell (no PATH edits needed)
Launch “MSYS2 MinGW64” and run your .exe from there (this shell already has the right PATH).

6. Verify GTK4 is present (optional) In MinGW64:

pkg-config --modversion gtk4

You should see a 4.x version. (This confirms the runtime is correctly installed.) packages.msys2.org (https://packages.msys2.org/package/mingw-w64-x86_64-gtk4?utm_source=chatgpt.com)

7. Run OCTAVie (Windows x64)
  - If you added PATH (step 5A): double-click your prebuilt OCTAVie.exe (e.g. in 4.software_pc\2.build\OCTAVie.exe).
  - If using the MinGW64 shell (step 5B):

cd /c/path/to/OCTAVie_FPGA_release/4.software_pc/2.build

./OCTAVie.exe

Notes and alternatives

Why MSYS2? It’s the GNOME/GTK-recommended route for GTK on Windows, and is how GTK4 binaries are distributed on Windows today. The GTK Team (https://www.gtk.org/docs/installations/windows?utm_source=chatgpt.com). Old “GTK runtime installers” you may find (e.g., tschoonj’s project) primarily target GTK2/GTK3 and are not maintained for GTK4; prefer the MSYS2 route for GTK4. GitHub+1 (https://github.com/tschoonj/gtk-for-windows-runtime-environment-installer/releases) . Bundling instead of installing: an alternative is to ship OCTAVie.exe with the required GTK4 DLLs in the same folder (portable ZIP or proper installer). This avoids asking users to install MSYS2, and is generally recommended for production distribution. GNOME Discourse+1 (https://discourse.gnome.org/t/convert-gtk4-project-to-exe-without-need-to-install-on-gtk4-on-customer-client/11115)

## A2) Quick “it works” checks (optional)

From MinGW64: gtk4-demo

If it launches, GTK4 is available and functional (the demo comes from the MSYS2 GTK4 package). packages.msys2.org (https://packages.msys2.org/package/mingw-w64-x86_64-gtk4?utm_source=chatgpt.com)

From CMD/PowerShell (only if you added PATH): where gtk4-demo

You should see it resolvable under C:\msys64\mingw64\bin\.

## A3) Common issues (and fixes)

- OCTAVie opens in MinGW64 shell but not by double-click → You likely didn’t add C:\msys64\mingw64\bin to PATH. Add it (A1-5A) or bundle DLLs. The GTK Team (https://www.gtk.org/docs/installations/windows?utm_source=chatgpt.com)
- “gtk-4-1.dll not found” or similar → Install mingw-w64-x86_64-gtk4 and ensure PATH includes C:\msys64\mingw64\bin. packages.msys2.org (https://packages.msys2.org/package/mingw-w64-x86_64-gtk4?utm_source=chatgpt.com)
- Multiple GTK installs conflicting → Ensure your PATH points to the mingw64 location first; remove/adjust older GTK entries.

# Case B — Develop & Recompile the Software (Windows x64)

Goal: build OCTAVie.exe from the source files using the provided Makefile.
This section explains how to install the full development environment (compiler + GTK4 libraries + tools) and verify the build.

## B1) Overview

The OCTAVie PC software is written in C and relies on GTK4 for its graphical interface.
The project includes a ready-to-use Makefile located in:

4.software_pc\1.sources\Makefile

It automatically compiles all source files (main.c, gui.c, io.c) and links them with the required GTK4 libraries. The resulting executable is named OCTAVie.exe.

⚠️ Before compiling, open the Makefile and verify that the compilation flags include
-DOS_WIN. This macro ensures that the source code is compiled for a Windows environment. Without it, certain system-dependent functions (e.g., threading or file access) may fail to compile or behave incorrectly.

## B2) Install MSYS2 (MinGW-w64 for Windows x64)

1. Download the latest 64-bit installer: 👉 https://www.msys2.org/
2. Run the installer and keep the default path:

C:\msys64

3. When installation finishes, open the MSYS2 MinGW64 terminal from the Start Menu (the window title should start with MINGW64).

## B3) Update and synchronize packages

In the MinGW64 terminal:

pacman -Syu

# If asked to close/reopen, do so, then:

pacman -Su

This ensures MSYS2 is fully up to date before you install the toolchain.

## B4) Install compiler, GTK4 development libraries, and tools

In the MinGW64 terminal (run each command line separately):

pacman -S mingw-w64-x86_64-toolchain

pacman -S mingw-w64-x86_64-gtk4

pacman -S mingw-w64-x86_64-pkg-config

pacman -S make git

These packages install:

- gcc/g++ — the C compiler for Windows x64
- GTK4 headers and libraries
- pkg-config — used by the Makefile to retrieve GTK compiler flags
- make — for building the project
- git (optional) — to clone the repository

## B5) Verify the installation

Run:

pkg-config --modversion gtk4

Expected output: a version number such as 4.14.3
(if you get an error, ensure you are in the MinGW64 shell, not plain MSYS).

You can also check the compiler:

gcc --version

## B6) Get the source code

If you don’t already have the project, clone it:

cd /c/path/to/your/workspace

git clone https://github.com/laura7durieux/OCTAVie_FPGA_release.git

Source folder for the PC software:

OCTAVie_FPGA_release/4.software_pc/1.sources/

## B7) Build the software

1. Enter the source directory:

cd /c/path/to/OCTAVie_FPGA_release/4.software_pc/1.sources

2. Compile using the Makefile:

make

The Makefile will:

- Compile each source file with:
- gcc -c `pkg-config gtk4 --cflags` <source>.c -D_REENTRANT -DOS_WIN
- Link all object files into one executable:
- gcc main.o gui.o io.o -o OCTAVie `pkg-config gtk4 --libs` -lm -lpthread
3. If everything is successful, you’ll see a new file:
4. OCTAVie.exe

## B8) Move the executable to the build folder (optional)

For consistency with the repository layout:

mkdir -p ../2.build

cp OCTAVie.exe ../2.build/OCTAVie.exe

## B9) Run the application

You can launch the software in two ways:

Option A — From the MinGW64 shell

cd ../2.build

./OCTAVie.exe

This uses the GTK4 libraries already available in C:\msys64\mingw64\bin.

Option B — Directly from Windows Explorer

If you prefer to double-click the .exe, ensure the GTK4 runtime is installed (as described in Case A) or add the following to your Windows PATH:

C:\msys64\mingw64\bin

## B10) Clean and rebuild

make clean

make

The clean rule removes all .o files so you can perform a fresh build.

## B11) Troubleshooting (build phase)

Error message | Possible cause | Fix
pkg-config: command not found | You’re in the wrong shell or missing the package | Use MSYS2 MinGW64 and install mingw-w64-x86_64-pkg-config
Package 'gtk4' not found | GTK4 dev libs missing | Run pacman -S mingw-w64-x86_64-gtk4
undefined reference to 'pthread_*' | Thread library linking issue | Ensure -lpthread is present or try -lwinpthread
rm not recognized | Running make clean from CMD | Run it inside the MinGW64 shell
.exe works only in shell | PATH missing GTK DLLs | Add C:\msys64\mingw64\bin to Windows PATH

## B12) Optional — Distribute a stand-alone build

To avoid requiring MSYS2 on user machines, you can bundle the following DLLs next to OCTAVie.exe (found in C:\msys64\mingw64\bin):

libgtk-4-1.dll

libgobject-2.0-0.dll

libglib-2.0-0.dll

libgio-2.0-0.dll

libgdk-4-1.dll

libcairo-gobject-2.dll

libcairo-2.dll

libpango-1.0-0.dll

libpangocairo-1.0-0.dll

Place them in the same folder as the executable (e.g., 4.software_pc\2.build\).
This makes OCTAVie fully portable on Windows x64.

## B13) Summary of commands (quick reference)

Commands to run in MSYS2 MinGW64 shell

pacman -Syu && pacman -Su

pacman -S mingw-w64-x86_64-toolchain mingw-w64-x86_64-gtk4 mingw-w64-x86_64-pkg-config make git

pkg-config --modversion gtk4

cd /c/path/to/workspace

git clone https://github.com/laura7durieux/OCTAVie_FPGA_release.git

cd OCTAVie_FPGA_release/4.software_pc/1.sources

make

mkdir -p ../2.build

cp OCTAVie.exe ../2.build/OCTAVie.exe

cd ../2.build

./OCTAVie.exe

# Clean rebuild

cd ../1.sources

make clean

make

Commands to run in Windows PowerShell

# (Optional) Temporary PATH for GTK4 DLLs

$env:Path = "C:\msys64\mingw64\bin;" + $env:Path

cd C:\path\to\OCTAVie_FPGA_release\4.software_pc\2.build

.\OCTAVie.exe

# License Information

Hardware license: CERN Open Hardware License v2 (Strongly Reciprocal – OHL-S).

Software license: GNU General Public License v3 (GPLv3), ensuring that all modifications remain open-source.

Documentation license: Creative Commons Attribution-ShareAlike 4.0 International (CC-BY-SA 4.0).

# Versioning

Authors | Version | Date | Comment
L. Durieux | V1.0 | 30.10.2025 | Document first release

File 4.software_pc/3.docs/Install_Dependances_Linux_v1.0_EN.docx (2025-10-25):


ie

JB Kammerer

Abstract

This document provides detailed instructions for installing and configuring the OCTAVie software environment on a Linux system. It includes the steps required to set up all necessary dependencies, such as GTK4 and related development libraries, to ensure proper compilation and execution of the graphical interface. The guide is intended to help users reproduce a functional environment quickly and avoid compatibility issues across distributions. Following these instructions guarantees that the OCTAVie software operates as intended on Linux-based systems.

InStall DependanceS Linux

English – v1.0

# Section 1 — Structure Generale

To be completed

# License Information

Hardware license: CERN Open Hardware License v2 (Strongly Reciprocal – OHL-S).

Software license: GNU General Public License v3 (GPLv3), ensuring that all modifications remain open-source.

Documentation license: Creative Commons Attribution-ShareAlike 4.0 International (CC-BY-SA 4.0).

# Versioning

Authors | Version | Date | Comment
JB Kammerer | V1.0 | 25.10.25 | Document first release

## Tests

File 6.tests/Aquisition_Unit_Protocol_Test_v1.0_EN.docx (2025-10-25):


ie

L. Durieux

Abstract

This document describes the protocol used to test and validate the OCTAVie acquisition unit. It details the steps required to verify correct data acquisition, signal processing, and communication with both the microphone module and the computer interface. The procedure includes hardware setup, input signal configuration, and output verification to ensure proper operation of the acquisition chain. Although this test is not mandatory for standard use, it can be useful to confirm system integrity, troubleshoot potential issues, or validate performance after assembly or modification.

acquisition Unit Protocol Test

English – v1.0

# Section 1 — Material needed

To be completed

# Section 2 — Protocol

To be completed

# License Information

Hardware license: CERN Open Hardware License v2 (Strongly Reciprocal – OHL-S).

Software license: GNU General Public License v3 (GPLv3), ensuring that all modifications remain open-source.

Documentation license: Creative Commons Attribution-ShareAlike 4.0 International (CC-BY-SA 4.0).

# Versioning

Authors | Version | Date | Comment
L. Durieux | V1.0 | 26.10.25 | Document first release

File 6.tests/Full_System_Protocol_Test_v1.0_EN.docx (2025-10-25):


ie

L. Durieux

Abstract

This document describes the complete testing protocol for the full OCTAVie system, including the microphone, acquisition unit, and software interface. It outlines the procedure to verify proper communication and synchronization between all subsystems, as well as to assess overall signal quality and system performance. The test includes setup instructions, signal generation, data recording, and result interpretation. Although not mandatory, this full-system test is highly recommended to confirm global functionality and ensure reliable operation before experimental use.

Full System Protocol Test

English – v1.0

# Section 1 — Material needed

To be completed

# Section 2 — Protocol

To be completed

# License Information

Hardware license: CERN Open Hardware License v2 (Strongly Reciprocal – OHL-S).

Software license: GNU General Public License v3 (GPLv3), ensuring that all modifications remain open-source.

Documentation license: Creative Commons Attribution-ShareAlike 4.0 International (CC-BY-SA 4.0).

# Versioning

Authors | Version | Date | Comment
L. Durieux | V1.0 | 26.10.25 | Document first release

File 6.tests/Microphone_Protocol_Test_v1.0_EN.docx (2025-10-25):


ie

L. Durieux

Abstract

This document describes the protocol used to test and validate the OCTAVie microphone module. It details the procedure for verifying microphone functionality, signal integrity, and communication with the acquisition system. The protocol includes hardware setup, test signal generation, data acquisition, and analysis methods to ensure proper operation of the microphone chain. Although this test is not mandatory for normal operation, it can be useful to confirm correct assembly, detect potential issues, or validate system performance before integration into the complete OCTAVie setup.

Microphone Protocol Test

English – v1.0

# Section 1 — Material needed

To be completed

# Section 2 — Protocol

To be completed

# License Information

Hardware license: CERN Open Hardware License v2 (Strongly Reciprocal – OHL-S).

Software license: GNU General Public License v3 (GPLv3), ensuring that all modifications remain open-source.

Documentation license: Creative Commons Attribution-ShareAlike 4.0 International (CC-BY-SA 4.0).

# Versioning

Authors | Version | Date | Comment
L. Durieux | V1.0 | 26.10.25 | Document first release

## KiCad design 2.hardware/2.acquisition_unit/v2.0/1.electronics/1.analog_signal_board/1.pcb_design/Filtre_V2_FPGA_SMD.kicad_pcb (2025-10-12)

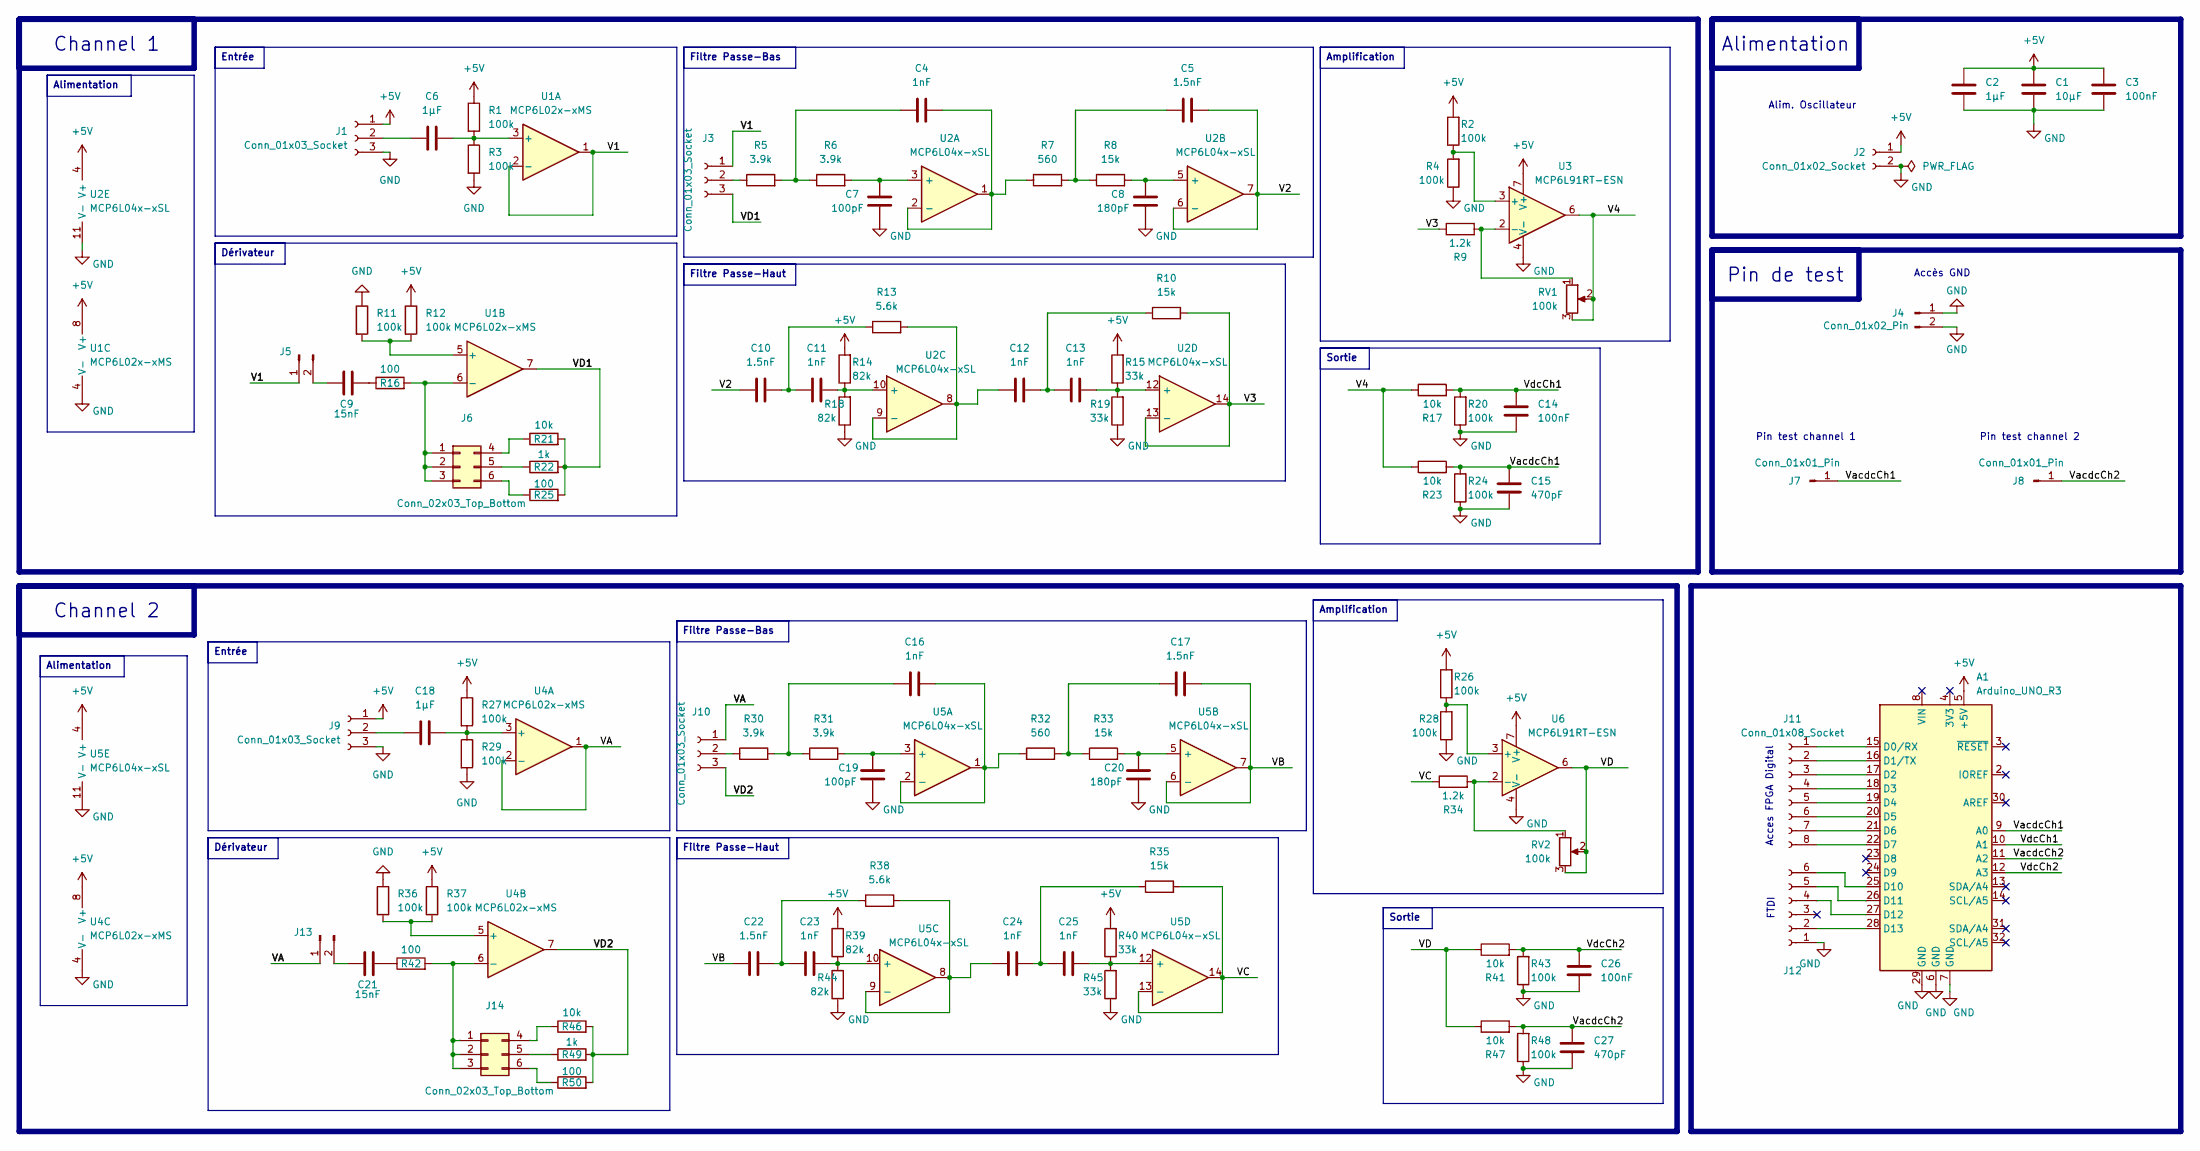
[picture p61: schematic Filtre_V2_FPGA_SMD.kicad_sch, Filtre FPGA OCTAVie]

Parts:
A1: Arduino_UNO_R3
C1: 10µF; C_0805_2012Metric; Manufacturer Part Number C0805C106K8PACTU
C2, C6, C18: 1µF; C_0805_2012Metric; Manufacturer Part Number C0805C105K3RAC7800
C3, C14, C26: 100nF; C_0805_2012Metric; Manufacturer Part Number C0805C104M5RAC7800
C4, C11, C12, C13, C16, C23, C24, C25: 1nF; C_0805_2012Metric; Manufacturer Part Number C0805C102K1HAC7800
C5, C10, C17, C22: 1.5nF; C_0805_2012Metric; Manufacturer Part Number C0805C152K3HAC7800
C7, C19: 100pF; C_0805_2012Metric; Manufacturer Part Number C0805C101J5GAC7800
C8, C20: 180pF; C_0805_2012Metric; Manufacturer Part Number C0805C181K5GAC7800
C9, C21: 15nF; C_0805_2012Metric; Manufacturer Part Number C0805C153K5RAC7800
C15, C27: 470pF; C_0805_2012Metric; Manufacturer Part Number C0805C471K5RAC7800
J1, J9: Conn_01x03_Socket; JST_XH_B3B-XH-AM_1x03_P2.50mm_Vertical; Manufacturer Part Number B3B-XH-A
J2: Conn_01x02_Socket; PinHeader_1x02_P2.54mm_Vertical; Manufacturer Part Number PH1-02-UA
J3, J10: Conn_01x03_Socket; PinHeader_1x03_P2.54mm_Vertical; Manufacturer Part Number PH1-03-UA
J4: Conn_01x02_Pin; PinHeader_1x02_P2.54mm_Vertical; Manufacturer Part Number PH1-02-UA
J5, J13: Conn_01x02_Pin; PinSocket_1x02_P2.54mm_Vertical; Manufacturer Part Number PH1-02-UA
J6, J14: Conn_02x03_Top_Bottom; PinHeader_2x03_P2.54mm_Vertical; Manufacturer Part Number PH2-06-UA
J7, J8: Conn_01x01_Pin; PinHeader_1x01_P2.54mm_Vertical; Manufacturer Part Number PH1-01-UA
J11: Conn_01x08_Socket; PinHeader_1x08_P2.54mm_Vertical; Manufacturer Part Number PH1-08-UA
J12: Conn_01x06_Socket; JST_XH_B6B-XH-A_1x06_P2.50mm_Vertical; Manufacturer Part Number B6B-XH-A
R1, R2, R3, R4, R11, R12, R20, R24, R26, R27, R28, R29, R36, R37, R43, R48: 100k; R_0805_2012Metric; Manufacturer Part Number ERJ-P06J104V
R5, R6, R30, R31: 3.9k; R_0805_2012Metric; Manufacturer Part Number ERJ-P06J392V
R7, R32: 560; R_0805_2012Metric; Manufacturer Part Number ERJ-P06J561V
R8, R10, R33, R35: 15k; R_0805_2012Metric; Manufacturer Part Number ERJ-P06J153V
R9, R34: 1.2k; R_0805_2012Metric; Manufacturer Part Number ERJ-P06J122V
R13, R38: 5.6k; R_0805_2012Metric; Manufacturer Part Number ERJ-P06J562V
R14, R18, R39, R44: 82k; R_0805_2012Metric; Manufacturer Part Number ERJ-P06J823V
R15, R19, R40, R45: 33k; R_0805_2012Metric; Manufacturer Part Number ERJ-P06J333V
R16, R25, R42, R50: 100; R_0805_2012Metric; Manufacturer Part Number ERJ-P06J101V
R17, R21, R23, R41, R46, R47: 10k; R_0805_2012Metric; Manufacturer Part Number ERJ-P06J103V
R22, R49: 1k; R_0805_2012Metric; Manufacturer Part Number ERJ-P06J102V
RV1, RV2: 100k; JST_XH_B3B-XH-AM_1x03_P2.50mm_Vertical; Manufacturer Part Number ERJ-P06J104V
U1, U4: MCP6L02x-xMS; SOIC-8_3.9x4.9mm_P1.27mm; Manufacturer Part Number MCP6022T-I/SN
U2, U5: MCP6L04x-xSL; SOIC-14_3.9x8.7mm_P1.27mm; Manufacturer Part Number MCP6024-I/SL
U3, U6: MCP6L91RT-ESN; SOIC-8_3.9x4.9mm_P1.27mm; Manufacturer Part Number MCP6021-I/SN

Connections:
+5V: A1.5 (+5V), C1.1, C2.1, C3.1, J1.1, J2.1, J9.1, R1.1, R2.2, R12.1, R14.2, R15.2, R26.2, R27.1, R37.1, R39.2, R40.2, U1.8 (V+), U2.4 (V+), U3.7 (V+), U4.8 (V+), U5.4 (V+), U6.7 (V+)
/V1: J3.1, J5.1, U1.1, U1.2 (-)
/V2: C5.2, C10.1, U2.6 (-), U2.7
/V3: R9.1, R10.2, U2.13 (-), U2.14
/V4: R17.1, R23.1, RV1.2, RV1.3, U3.6
/VA: J10.1, J13.1, U4.1, U4.2 (-)
/VB: C17.2, C22.1, U5.6 (-), U5.7
/VC: R34.1, R35.2, U5.13 (-), U5.14
/VD: R41.1, R47.1, RV2.2, RV2.3, U6.6
/VD1: J3.3, R21.2, R22.2, R25.2, U1.7
/VD2: J10.3, R46.2, R49.2, R50.2, U4.7
/VacdcCh1: A1.9 (A0), C15.2, J7.1, R23.2, R24.2
/VacdcCh2: A1.11 (A2), C27.2, J8.1, R47.2, R48.2
/VdcCh1: A1.10 (A1), C14.2, R17.2, R20.2
/VdcCh2: A1.12 (A3), C26.2, R41.2, R43.2
GND: A1.6 (GND), A1.7 (GND), A1.29 (GND), C1.2, C2.2, C3.2, C7.1, C8.1, C14.1, C15.1, C19.1, C20.1, C26.1, C27.1, J1.3, J2.2, J4.1, J4.2, J9.3, J12.1, R3.2, R4.1, R11.1, R18.1, R19.1, R20.1, R24.1, R28.1, R29.2, R36.1, R43.1, R44.1, R45.1, R48.1, U1.4 (V-), U2.11 (V-), U3.4 (V-), U4.4 (V-), U5.11 (V-), U6.4 (V-)
unnamed: A1.15 (D0/RX), J11.1
unnamed: A1.16 (D1/TX), J11.2
unnamed: A1.17 (D2), J11.3
unnamed: A1.18 (D3), J11.4
unnamed: A1.19 (D4), J11.5
unnamed: A1.20 (D5), J11.6
unnamed: A1.21 (D6), J11.7
unnamed: A1.22 (D7), J11.8
unnamed: A1.25 (D10), J12.6
unnamed: A1.26 (D11), J12.5
unnamed: A1.27 (D12), J12.4
unnamed: A1.28 (D13), J12.2
unnamed: C4.1, R5.2, R6.1
unnamed: C5.1, R7.2, R8.1
unnamed: C9.2, R16.1
unnamed: C10.2, C11.1, R13.1
unnamed: C12.2, C13.1, R10.1
unnamed: C16.1, R30.2, R31.1
unnamed: C17.1, R32.2, R33.1
unnamed: C21.2, R42.1
unnamed: C22.2, C23.1, R38.1
unnamed: C24.2, C25.1, R35.1
unnamed: C6.1, J1.2
unnamed: J3.2, R5.1
unnamed: C9.1, J5.2
unnamed: J6.1, J6.2, J6.3, R16.2, U1.6 (-)
unnamed: J6.4, R21.1
unnamed: J6.5, R22.1
unnamed: J6.6, R25.1
unnamed: C18.1, J9.2
unnamed: J10.2, R30.1
unnamed: C21.1, J13.2
unnamed: J14.1, J14.2, J14.3, R42.2, U4.6 (-)
unnamed: J14.4, R46.1
unnamed: J14.5, R49.1
unnamed: J14.6, R50.1
unnamed: C6.2, R1.2, R3.1, U1.3 (+)
unnamed: R11.2, R12.2, U1.5 (+)
unnamed: C7.2, R6.2, U2.3 (+)
unnamed: C4.2, R7.1, U2.1, U2.2 (-)
unnamed: C8.2, R8.2, U2.5 (+)
unnamed: C11.2, R14.1, R18.2, U2.10 (+)
unnamed: C12.1, R13.2, U2.8, U2.9 (-)
unnamed: C13.2, R15.1, R19.2, U2.12 (+)
unnamed: R2.1, R4.2, U3.3 (+)
unnamed: R9.2, RV1.1, U3.2 (-)
unnamed: C18.2, R27.2, R29.1, U4.3 (+)
unnamed: R36.2, R37.2, U4.5 (+)
unnamed: C19.2, R31.2, U5.3 (+)
unnamed: C16.2, R32.1, U5.1, U5.2 (-)
unnamed: C20.2, R33.2, U5.5 (+)
unnamed: C23.2, R39.1, R44.2, U5.10 (+)
unnamed: C24.1, R38.2, U5.8, U5.9 (-)
unnamed: C25.2, R40.1, R45.2, U5.12 (+)
unnamed: R26.1, R28.2, U6.3 (+)
unnamed: R34.2, RV2.1, U6.2 (-)

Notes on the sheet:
Alim. Oscillateur
FTDI
Pin test channel 1
Accès GND
Acces FPGA Digital
Pin test channel 2
Alimentation
Filtre Passe-Bas
Dérivateur
Entrée
Amplification
Filtre Passe-Haut
Channel 2
Channel 1
Sortie
Pin de test

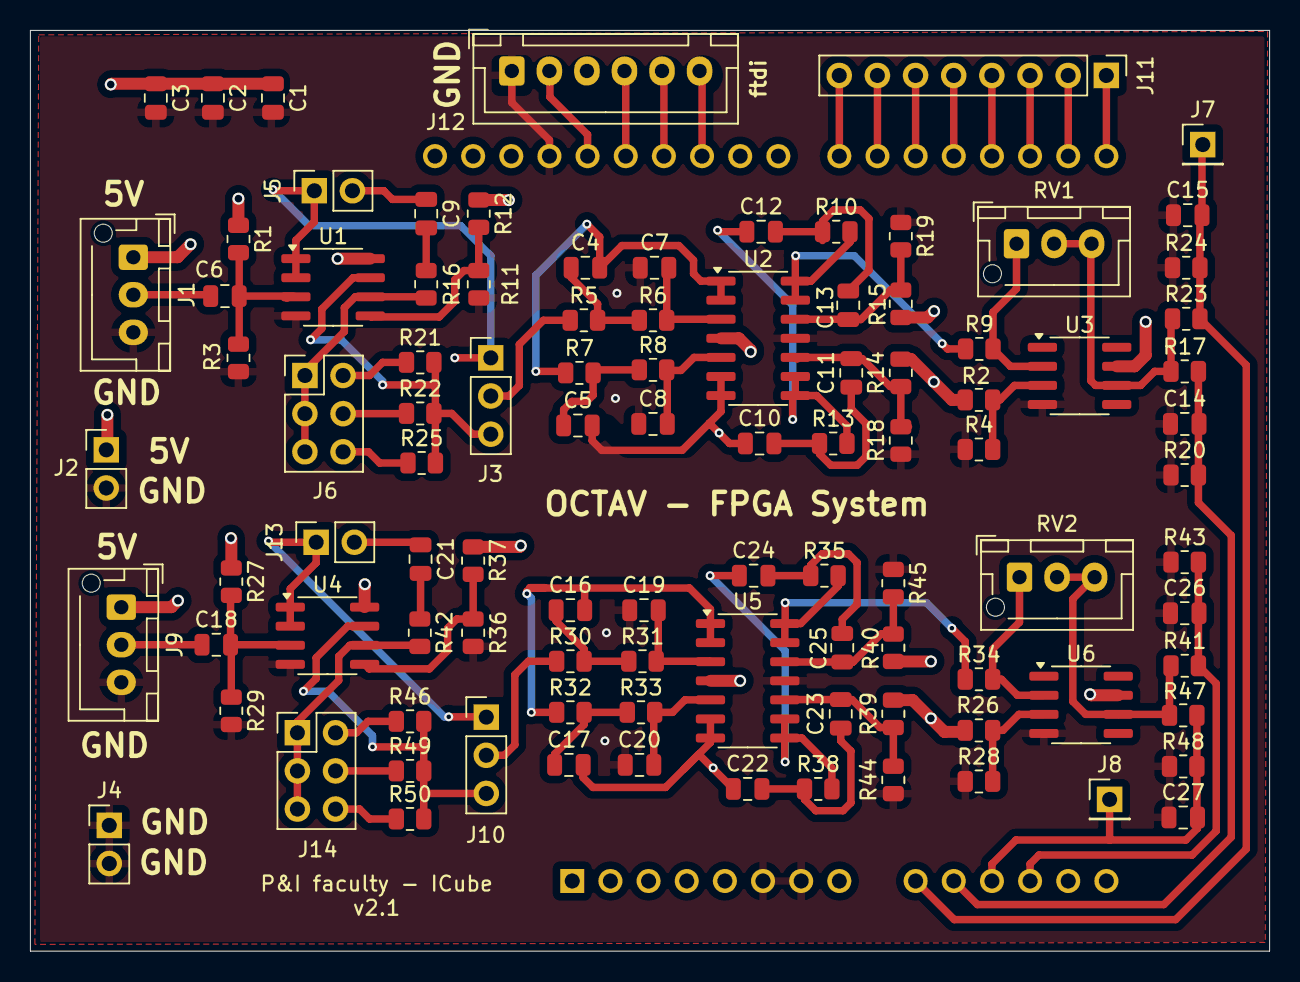
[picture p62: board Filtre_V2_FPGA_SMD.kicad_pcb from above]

Board: 4 copper layers, 82.5 x 61.3 mm, 100 parts (1 on the bottom side), 72 nets.

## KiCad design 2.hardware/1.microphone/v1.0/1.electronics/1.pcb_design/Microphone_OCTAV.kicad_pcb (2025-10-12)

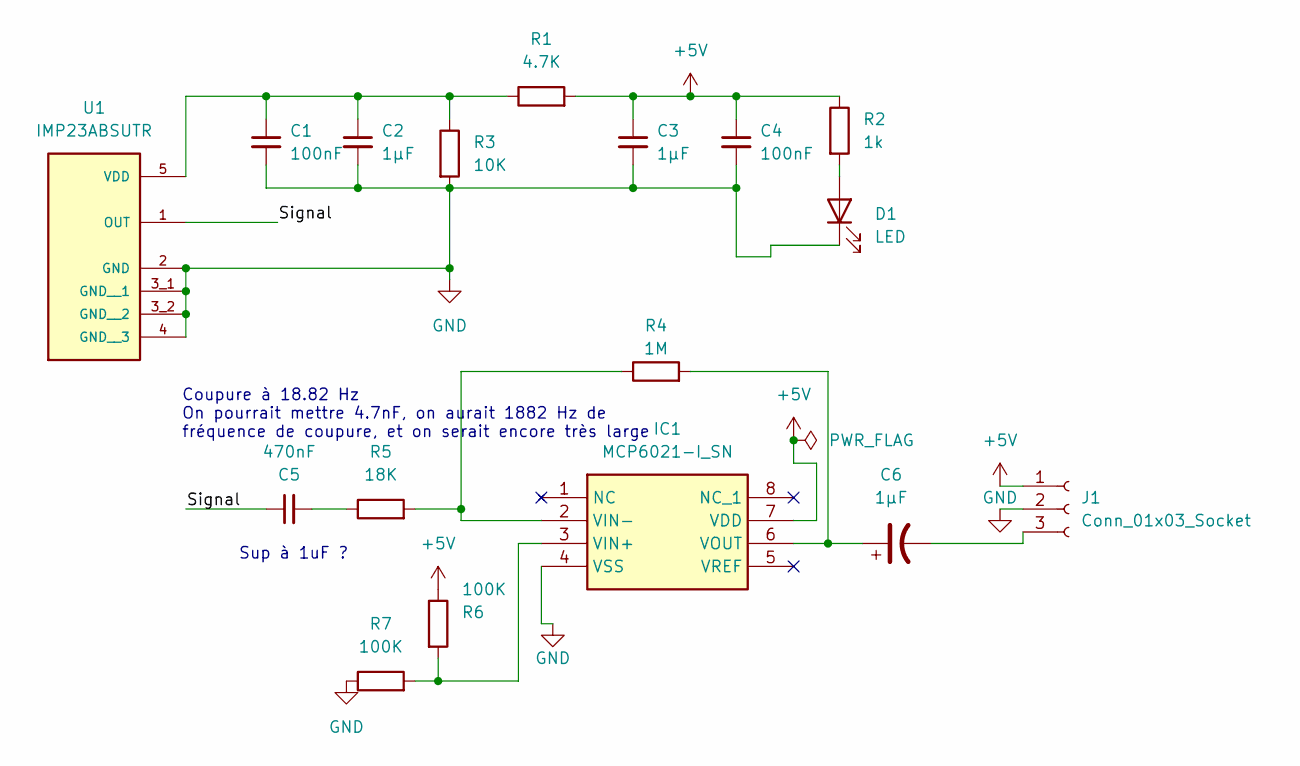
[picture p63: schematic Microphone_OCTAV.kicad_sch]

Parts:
C1, C4: 100nF; C_0805_2012Metric; Manufacturer_Part_Number C0805C104K5RACTU
C2, C3, C6: 1µF; C_0805_2012Metric; Manufacturer_Part_Number C0805C105K3RACTU
C5: 470nF; C_0805_2012Metric; Manufacturer_Part_Number C0805C474K5RACTU
D1: LED; LED_0805_2012Metric; Manufacturer_Part_Number 150080RS75000
IC1: MCP6021-I_SN; SOIC127P600X175-8N; Mouser Part Number 579-MCP6021-I/SN
J1: Conn_01x03_Socket; CONN_B3B-PH-SM4-TB_03P_JST; Manufacturer_Part_Number B3B-PH-SM4-TB
R1: 4.7K; R_0805_2012Metric; Manufacturer_Part_Number AC0805FR-074K7L
R2: 1k; R_0805_2012Metric; Manufacturer_Part_Number RC0805JR-071KL
R3: 10K; R_0805_2012Metric; Manufacturer_Part_Number RC0805JR-0710KL
R4: 1M; R_0805_2012Metric; Manufacturer_Part_Number RC0805JR-071ML
R5: 18K; R_0805_2012Metric; Manufacturer_Part_Number RC0805JR-0718KL
R6, R7: 100K; R_0805_2012Metric; Manufacturer_Part_Number RC0805JR-07100KL
U1: IMP23ABSUTR; MIC_IMP23ABSUTR; PARTREV 2

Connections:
+5V: C3.1, C4.1, IC1.7 (VDD), J1.1, R1.2, R2.1, R6.1
/Signal: C5.1, U1.1 (OUT)
GND: C1.2, C2.2, C3.2, C4.2, D1.1 (K), IC1.4 (VSS), J1.2, R3.2, R7.1, U1.2 (GND), U1.3_1 (GND__1), U1.3_2 (GND__2), U1.4 (GND__3)
unnamed: C5.2, R5.1
unnamed: D1.2 (A), R2.2
unnamed: IC1.3 (VIN+), R6.2, R7.2
unnamed: IC1.2 (VIN-), R4.1, R5.2
unnamed: C6.1, IC1.6 (VOUT), R4.2
unnamed: C6.2, J1.3
unnamed: C1.1, C2.1, R1.1, R3.1, U1.5 (VDD)

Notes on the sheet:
Sup à 1uF ?
Coupure à 18.82 Hz On pourrait mettre 4.7nF, on aurait 1882 Hz de fréquence de coupure, et on serait encore très large

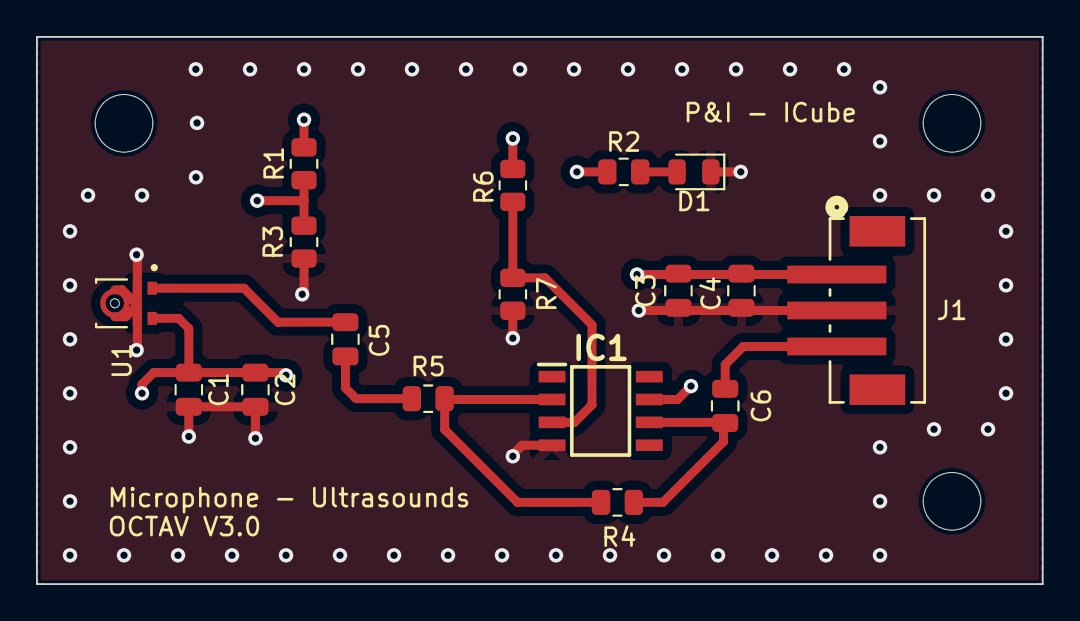
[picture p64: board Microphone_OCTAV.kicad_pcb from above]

Board: 4 copper layers, 55.9 x 30.4 mm, 17 parts (0 on the bottom side), 10 nets.

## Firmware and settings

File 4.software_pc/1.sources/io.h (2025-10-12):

#ifndef IO_H
#define IO_H

#include "gui.h"
#include "msg.h"
//***************************************************
// Define
//***************************************************

//#define OS_POSIX
//#define OS_WIN

#define DEFAULT_COM_PORT 0
#ifdef OS_POSIX
#define DEFAULT_LINUX_COM_PORT_PATH "/dev/ttyUSB"
#endif
#ifdef OS_WIN
#define DEFAULT_LINUX_COM_PORT_PATH "\\\\.\\COM"
#endif
#define DEFAULT_OUTPUT_FILE "FFT_data.csv"

#define COM_OPEN_ERROR -1

//***************************************************
// Prototypes
//***************************************************

// COM port reading thread
void* read_com(void* data);

// File transfert function
void* record_data(void* data);

// File transfert function
void* update_graph(void* data);

#endif

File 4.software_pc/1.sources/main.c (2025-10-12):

#include <gtk/gtk.h>
#include <gtk/gtkpicture.h>
#include <stdlib.h>
#include <stdio.h>
#include <math.h>

#include "gui.h"
#include "io.h"
#include "msg.h"

int main(int argc, char* argv[])
{
    int status;
    
    // common data
    AppState state;
    
    // Init state
    state.output_file == NULL;
    
    // data buffers
    state.buffer_filled = 1;
    if((state.data_buffer[0]=malloc(DATA_BUFFER_SIZE))==NULL)
    {
        perror(ERR_MAIN);
        exit(1);
    }
    if((state.data_buffer[1]=malloc(DATA_BUFFER_SIZE))==NULL)
    {
        perror(ERR_MAIN);
        exit(1);
    }
    
    // multi-threading mutex
    if(pthread_mutex_init(&state.read_com_mutex, NULL))
    {   
        perror(ERR_MAIN);
        exit(EXIT_FAILURE);
    }    
    if(pthread_mutex_init(&state.record_data_mutex, NULL))
    {   
        perror(ERR_MAIN);
        exit(EXIT_FAILURE);
    }
    if(pthread_mutex_init(&state.update_graph_mutex, NULL))
    {   
        perror(ERR_MAIN);
        exit(EXIT_FAILURE);
    }

    // COM port reading thread
    if(pthread_create(&state.read_com_th, NULL, read_com, &state))
    {
        perror(ERR_MAIN);
        exit(EXIT_FAILURE);
    }
    // File transfering thread
    if(pthread_create(&state.record_data_th, NULL, record_data, &state))
    {
        perror(ERR_MAIN);
        exit(EXIT_FAILURE);
    }
    // Update graph thread
    if(pthread_create(&state.update_graph_th, NULL, update_graph, &state))
    {
        perror(ERR_MAIN);
        exit(EXIT_FAILURE);
    }
    
    // Create a new GTK application
    GtkApplication *app = gtk_application_new("com.OCTAVie", G_APPLICATION_DEFAULT_FLAGS);
    if (!G_IS_OBJECT(app)) {
            perror(ERR_MAIN);
            g_printerr("Error: Failed to initialize GtkApplication\n");
            return EXIT_FAILURE;
        }

    g_signal_connect(app, "activate", G_CALLBACK(app_activated_cb), &state);

    // Run the GTK application
    status = g_application_run(G_APPLICATION(app), argc, argv);
    // Unref the application object
    g_object_unref(app);
    
    // stop all threads
    // mutex lock
    if(pthread_mutex_lock(&state.read_com_mutex))
    {
        perror(ERR_MAIN);
        exit(EXIT_FAILURE);
    }
    state.read_com_please_quit = TRUE;
    state.read_com_call = TRUE;
    if(pthread_cond_signal(&state.read_com_cond))
    {
        perror(ERR_MAIN);
        exit(EXIT_FAILURE);
    }
    if(pthread_mutex_unlock(&state.read_com_mutex))
    {
        perror(ERR_MAIN);
        exit(EXIT_FAILURE);
    }
    //
    if(pthread_mutex_lock(&state.record_data_mutex))
    {
        perror(ERR_MAIN);
        exit(EXIT_FAILURE);
    }
    state.record_data_please_quit = TRUE;
    state.record_data_call = TRUE;
    if(pthread_cond_signal(&state.record_data_cond))
    {
        perror(ERR_MAIN);
        exit(EXIT_FAILURE);
    }   
    if(pthread_mutex_unlock(&state.record_data_mutex))
    {
        perror(ERR_MAIN);
        exit(EXIT_FAILURE);
    }
    //
    if(pthread_mutex_lock(&state.update_graph_mutex))
    {
        perror(ERR_MAIN);
        exit(EXIT_FAILURE);
    }
    state.update_graph_please_quit = TRUE;
    state.update_graph_call = TRUE;
    if(pthread_cond_signal(&state.update_graph_cond))
    {
        perror(ERR_MAIN);
        exit(EXIT_FAILURE);
    }
    if(pthread_mutex_unlock(&state.update_graph_mutex))
    {
        perror(ERR_MAIN);
        exit(EXIT_FAILURE);
    }
    
    
    // multi-threading end
    pthread_join(state.read_com_th, NULL);
    pthread_join(state.record_data_th, NULL);
    pthread_join(state.update_graph_th, NULL);
    pthread_mutex_destroy(&state.read_com_mutex);
    pthread_mutex_destroy(&state.record_data_mutex);
    pthread_mutex_destroy(&state.update_graph_mutex);
    pthread_cond_destroy(&state.read_com_cond);
    pthread_cond_destroy(&state.record_data_cond);
    pthread_cond_destroy(&state.update_graph_cond);
    
    // free buffers
    free(state.data_buffer[0]);
    free(state.data_buffer[1]);
    // end
    return(EXIT_SUCCESS);
}

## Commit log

2025-10-12 Build microphone tutorial add up
    [File_list_v1.0.xlsx]
2025-10-25 udapte docs
    [FFT_data.csv, FFT_data_example_format_v1.0_EN.csv, File_list_v1.0.xlsx]
2025-10-29 Update VHDL
    Update comments on vhdl file + Writing the schematic doc explanation
    [File_list_v1.0.xlsx]
2025-11-01 General Review
    [2025-08-28T005223_panier DIGIKEY.csv, 2025-08-28T005223_panier DIGIKEY.xlsx, File_list_v1.0.xlsx]
